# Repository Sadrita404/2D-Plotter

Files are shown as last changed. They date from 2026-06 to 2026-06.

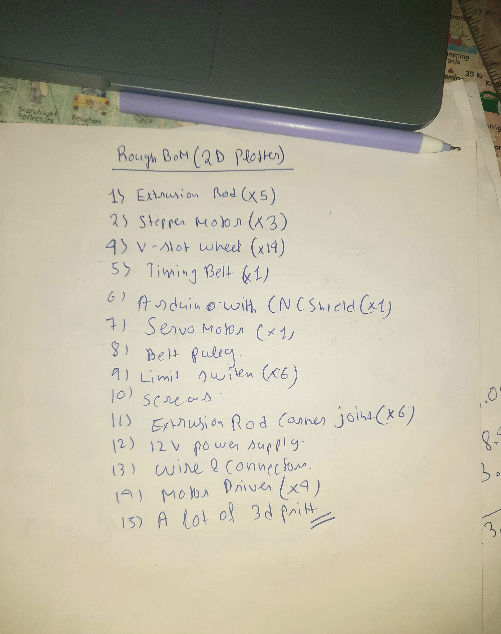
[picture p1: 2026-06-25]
IMAGE/rough BOM.jpg

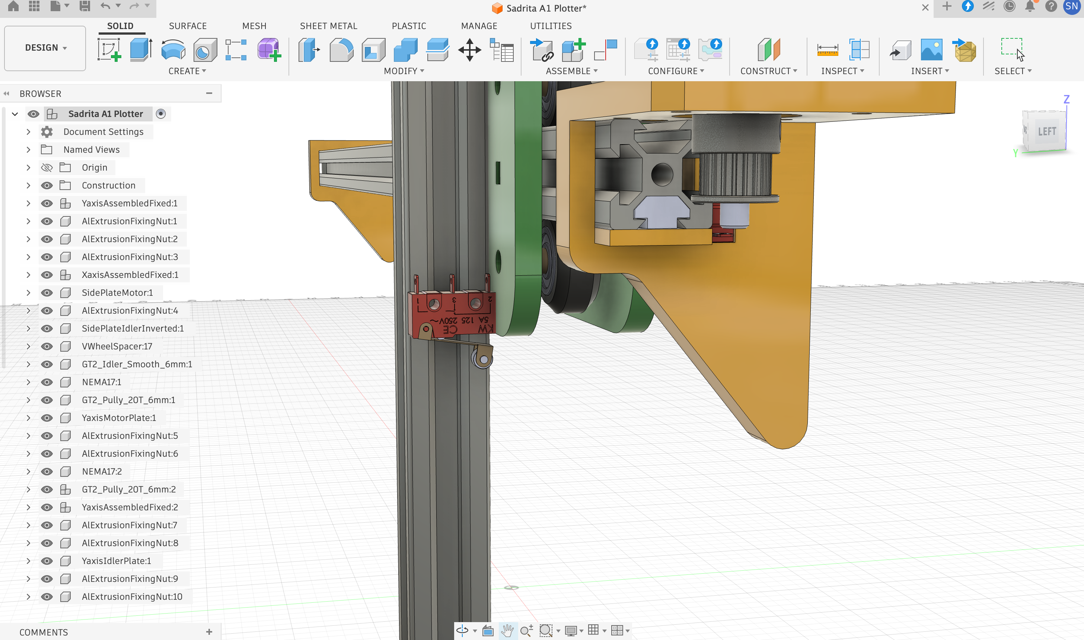
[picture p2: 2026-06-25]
IMAGE/39.png

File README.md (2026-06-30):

|Title | 2D Plotter |
|:-- |:--|
|Author | Sadrita Neogi|

## Overview

It's an hobby grade Pen Plotter which can plot upto A1 size pages and will be efficient to use . It is also very reliable to use it uses grbl software.I have made it open source and anyone can recreate this and also customize it as all the step files are provided . This is made up of 2020 Extrusion Rod with Nema 17 stepper Motor..

### Why I chose this project?
I have choosing this project since it's my from a long time. I have think about that. I want to build and pen plotter. Since whenever I seen this kind of plotted video in any social media, it just fascinated me like how it can just recreate the exact same copy that is on the desktop. So I have chosen this project since I have dream about this project and I like the concept, how the project works, how we can control the coordinates and make changes in the design.

### How to use this project
Use case of this project can be many according to the need, but for my I want to create stunning drawings that cannot be achieved by manually if possible, then it would take many hours, but then I can easily recreate this using this slaughter and also I am very fascinated about drawing about the blueprint of any structure, so it would be great. I can make blueprint of any structured using it since it can easily feed big size pages.

### Rough Sketch

sketch
<p align="center">
  
</p>

<div align="center">

|  | CAD WORK |  |  
| :-: | :-: | :-: |
| CAD Work 7 | CAD Work 11 | CAD Work 18 |
| CAD Work 22 | CAD Work 25 | CAD Work 29 |
| CAD Work 32 | CAD Work 34 | CAD Work 36 |
| CAD Work 39 | CAD Work 42 | CAD Work 47 |
| CAD Work 49 | CAD Work 51 | CAD Work 52 |

</div>

---

## Wiring Diagram 

<p align="center">
  
</p>

## Setup

Once the machine is assembled and wired, firmware needs to be installed so that it can move.

### Flashing GRBL onto the Arduino
GRBL is the firmware which is going to run on the Arduino and interpret the G-code commands. The installation is fairly simple.

1. **Download the Arduino IDE** from their site, a program which allows to flash the Arduino with firmware.
2. **Download GRBL source code** `.zip` file from the GitHub repository: https://github.com/gnea/grbl/releases and unzip the grbl file.  
**Note:** Before we proceed, we need to modify the `config.h` file inside grbl to account for the lack of the Z axis.
3. **Open Arduino IDE and import the grbl file** via: `Sketch` -> `Include Library` -> `Add .ZIP Library...` *(it says .ZIP but the uncompressed file should be chosen)*.
4. **Navigate to the grblUpload sketch** via: `File` -> `Examples` -> `grbl` -> `grblUpload`.
5. **Connect the Arduino to the PC via USB** *(make sure the correct board and port is selected)*.
6. **Flash the sketch** through `Sketch` -> `Upload`.

### For more about the CNC shield - [DOC Link](https://mikroshop.ch/pdf/CNC-Shield-Guide.pdf)
---

### Connecting the Arduino to LaserGRBL
Connecting the Arduino to LaserGRBL (through which I will control the laser) is fairly simple.

1. **Download LaserGRBL** from their website: https://lasergrbl.com and install it.
2. **Connect the Arduino to the computer via USB**.
3. **Choose the correct port** and select **"115200" baud rate**, then click **Connect**.  

If the console shows `Grbl 1.1h`, the chip is connected.

##  Now for sending the G- Code to the Arduino I will use universal Gcode Sender 

**https://github.com/winder/Universal-G-Code-Sender**

- official website - https://winder.github.io/ugs_website/

- It is an open source software, which is used to control CNC machines to send G code to them and to use it

---

## Final Look ( Made in Fusion 360 )

<div align="center">









</div>

<div align="center">
  <h2> Bill of Materials</h2>
</div>

| Name | Purpose | Quantity | Total Cost (USD) | Link | Distributor |
| :--- | :--- | :---: | :---: | :--- | :--- |
| 3.5mm Cylindrical Plastic Spacer | For the Pulley | 1 | 2.76 | [Link](https://onlyscrews.in/products/cylindrical-plastic-spacer-assorted-pack-for-m3-screws) | onlyscrews |
| GT2 Open Loop Timing Belt | For the Pulley | 1 | 4.45 | [Link](https://robu.in/product/5-meter-x-gt2-open-timing-belt-6mm-width/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) | robu |
| Stepper Motor Cable extended | Cable with Connector for NEMA17 Stepper Motor | 3 | 1.40 | [Link](https://robu.in/product/pure-copper-1000-mm-cable-with-connector-for-nema17-stepper-motor/) | robu |
| Extrusion corner bracket | For the Extrusion Rod | 1 | 2.49 | [Link](https://robu.in/product/easymech-cast-corner-bracket-for-20x20-aluminium-profile-silver-4-pcs/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) | robu |
| Cable spiral wrap | For the Cable Protection | 3 | 2.75 | [Link](https://robu.in/product/black-insulated-braid-sleeving-tight-pet-wire-cable-protection-expandable-cable-sleeve-wire-gland/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) | robu |
| Multistrand wire | For the circuit | 2 | 8.51 | [Link](https://robu.in/product/14awg-multicore-insulated-cable3-cores-silicone/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) | robu |
| M5 Nyloc nuts | For the Frame | 20 | 0.25 | [Link](https://onlyscrews.in/products/m5-nyloc-nuts-mild-steel-with-zinc-plating-dia-5mm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) | onlyscrews |
| M3 5mm | For the stepper motor | 20 | 0.35 | [Link](https://onlyscrews.in/products/m3-x-5mm-phillips-pan-head-ss-304-screw-dia-3mm-length-5mm) | onlyscrews |
| M5 X 40mm Hex Bolt | For the Frame | 20 | 1.31 | [Link](https://onlyscrews.in/products/m5-x-40mm-hex-bolt-ss304-dia-5mm-length-40mm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) | onlyscrews |
| M5 Bolts | For the frame | 25 | 3.39 | [Link](https://onlyscrews.in/products/m5-phillips-pan-head-ss304-assorted-box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) | onlyscrews |
| M5 Sliding Nuts | For the 2020 Extrusion Rod | 20 | 1.91 | [Link](https://onlyscrews.in/products/m4-profile-nuts-mild-steel-with-nickel-plating-for-3030-series-t-nut-hammer-nut-1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) | onlyscrews |
| Aluminium Spacer (M5) | For the Pulley | 4 | 4.19 | [Link](https://robu.in/product/lot-aluminium-spacer-5x8mm-7mm-width-silver-4pcs/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) | robu |
| 10mm Spring (ID 5mm) | For the pen holder | 12 | 0.64 | [Link](https://onlyscrews.in/products/od-5mm-free-length-10mm-wire-dia-0-6mm-compression-spring-stainless-steel-304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) | onlyscrews |
| M5 X 45mm Hard Dowel Pins | For the pulley | 20 | 1.91 | [Link](https://onlyscrews.in/products/m5-x-45mm-hard-dowel-pins-dia-5mm-length-45mm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) | onlyscrews |
| 12V 3A power supply | For Power | 1 | 5.59 | [Link](https://robu.in/product/standard-12v-3a-power-supply-with-5-5mm-dc-plug-desktop-type/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) | robu |
| Pin sockets | For Connection | 2 | 0.23 | [Link](https://robu.in/product/2-54mm-1x40-pin-female-single-row-header-strip-pack-of-10/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) | robu |
| JST wire connectors | For the connector | 4 | 1.48 | [Link](https://robu.in/product/jst-xh-2-54mm-4-pin-female-housing-connector/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) | robu |
| JST 4-pin connectors | For Connection | 12 | 1.65 | [Link](https://robu.in/product/4-pin-jst-xh-2-54mm-pitch-plug-and-socket-with-cable-5-pcs/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) | robu |
| JST 3-pin connectors | For the Connection | 12 | 1.52 | [Link](https://robu.in/product/3-pin-jst-xh-2-54mm-pitch-plug-and-socket-with-cable-10-pcs/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) | robu |
| Endstop Switch | For the limit end | 6 | 2.99 | [Link](https://robu.in/product/cnc-3d-printer-mech-endstop-switch/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) | robu |
| A4988 driver Stepper Motor Driver | For the CNC Shield | 3 | 3.97 | [Link](https://robu.in/product/a4988-driver-stepper-motor-driver/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) | robu |
| GT2 5mm Bore Aluminum Pulley Without Teeth | For the belt to move | 8 | 6.12 | [Link](https://www.flyrobo.in/gt2-5mm-bore-aluminum-pulley-without-20-teeth-for-6mm-belt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) | flyrobo |
| GT2 Pulley 20 Teeth 5mm for 6mm | For drive the belt | 4 | 1.08 | [Link](https://robu.in/product/gt2-6mm-belt-width-20-teeth-5mm-bore-timing-pulley/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) | robu |
| SG90 Servo Motor | For the Pen Movement | 1 | 1.55 | [Link](https://robu.in/product/towerpro-sg90-9gm-1-2kg-180-degree-rotation-servo-motor-good-quality/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) | robu |
| CNC Shield V3 | CNC Control Boa | 1 | 1.60 | [Link](https://www.flyrobo.in/cnc-shield-v3-for-engraving-machine-3d-printer-a4988-drv8825-driver-expansion-board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) | flyrobo |
| Arduino Uno | The Main Board | 1 | 2.28 | [Link](https://robu.in/product/arduino-uno-r3-ch340g-atmega328p-devlopment-board/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) | robu |
| GT2 Timing Belt 6mm | For Gantry System | 1 | 6.66 | [Link](https://robu.in/product/10m-gt2-width-6mm-white-open-timing-belt-for-3d-printer/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) | robu |
| V-Slot Idler Pulley | For Gantry System | 14 | 9.20 | [Link](https://www.flyrobo.in/openbuilds-plastic-wheel-idler-pulley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) | flyrobo |
| Nema 17 Bipolar Stepper Motor | The Main Motor | 3 | 40.90 | [Link](https://robu.in/product/fulling-fl42sth38-1684a-nema-17-stepper-motor/) | robu |
| 2020 Aluminium Extrusion | For the Frame | 5 | 37.09 | [Link](https://robu.in/product/easymech-20x20-t-slot-aluminium-extrusion-profile-1500-mm/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) | robu |

<div align="center">
  <table border="0" cellpadding="0" cellspacing="0" style="border-collapse: collapse; max-width: 600px;">
    <tr>
      <td style="background: #ffffff; border: 1px solid #d0d7de; border-radius: 12px; padding: 20px; box-shadow: 0 4px 12px rgba(0,0,0,0.05); font-family: -apple-system, BlinkMacSystemFont, 'Segoe UI', Helvetica, Arial, sans-serif;">
        <div style="font-size: 16px; font-weight: 600; color: #24292f; margin-bottom: 12px; border-bottom: 1px solid #d0d7de; padding-bottom: 8px;">
          Final Bill
        </div>
        <table width="100%" border="0" style="border-collapse: collapse; font-size: 14px; color: #57606a;">
          <tr>
            <td style="padding: 4px 0;">Component Subtotal:</td>
            <td align="right" style="font-weight: 500; color: #24292f;">$160.22</td>
          </tr>
          <tr>
            <td style="padding: 4px 0;"> Shipping:</td>
            <td align="right" style="font-weight: 500; color: #24292f;">$4.2</td>
          </tr>
          <tr>
            <td style="padding: 4px 0; padding-bottom: 8px;"> Tax:</td>
            <td align="right" style="font-weight: 500; color: #24292f;">$5.1</td>
          </tr>
          <tr style="border-top: 1px dashed #d0d7de;">
            <td style="padding: 12px 0 0 0; font-weight: 600; color: #24292f; font-size: 15px;">Net Total Cost:</td>
            <td align="right" style="padding: 12px 0 0 0; font-weight: bold; color: #2da44e; font-size: 18px;">$169.52</td>
          </tr>
          <tr>
            <td style="padding: 2px 0 0 0; font-size: 11px; color: #8c959f;">Projected Budget Allocation:</td>
            <td align="right" style="padding: 2px 0 0 0; font-weight: 500; font-size: 12px; color: #8c959f;">$170</td>
          </tr>
        </table>
      </td>
    </tr>
  </table>
</div>

#### Please approve this project I had put a lot of work in making it.

**Project Under Hack Club**

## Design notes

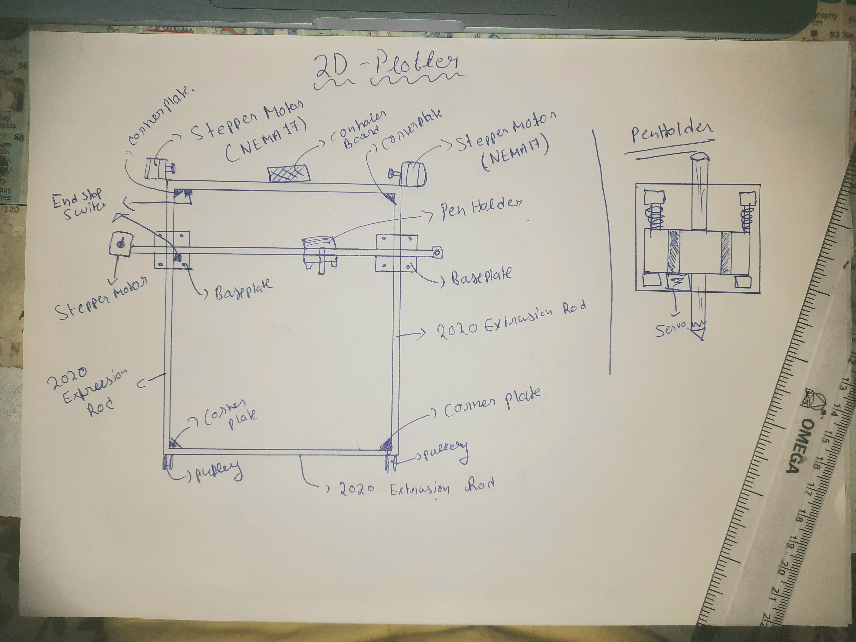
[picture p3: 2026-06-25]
IMAGE/sketch.jpg

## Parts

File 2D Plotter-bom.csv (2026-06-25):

Name | Purpose | Quantity | Total Cost (USD) | Link | Distributor
3.5mm Cylindrical Plastic Spacer | For the Pulley | 1 | 2.76 | https://onlyscrews.in/products/cylindrical-plastic-spacer-assorted-pack-for-m3-screws | onlyscrews
GT2 Open Loop Timing Belt | For the Pulley | 1 | 4.45 | https://robu.in/product/5-meter-x-gt2-open-timing-belt-6mm-width/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 | robu
Stepper Motor Cable extended | Cable with Connector for NEMA17 Stepper Motor | 3 | 1.40 | https://robu.in/product/pure-copper-1000-mm-cable-with-connector-for-nema17-stepper-motor/ | robu
Extrusion corner bracket | For the Extrusion Rod | 1 | 2.49 | https://robu.in/product/easymech-cast-corner-bracket-for-20x20-aluminium-profile-silver-4-pcs/?gad_source=1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 | robu
Cable spiral wrap | For the Cable Protection | 3 | 2.75 | https://robu.in/product/black-insulated-braid-sleeving-tight-pet-wire-cable-protection-expandable-cable-sleeve-wire-gland/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 | robu
Multistrand wire | For the circuit | 2 | 8.51 | https://robu.in/product/14awg-multicore-insulated-cable3-cores-silicone/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 | robu
M5 Nyloc nuts | For the Frame | 20 | 0.25 | https://onlyscrews.in/products/m5-nyloc-nuts-mild-steel-with-zinc-plating-dia-5mm?currency=INR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 | onlyscrews
M3 5mm | For the stepper motor | 20 | 0.35 | https://onlyscrews.in/products/m3-x-5mm-phillips-pan-head-ss-304-screw-dia-3mm-length-5mm | onlyscrews
M5 X 40mm Hex Bolt | For the Frame | 20 | 1.31 | https://onlyscrews.in/products/m5-x-40mm-hex-bolt-ss304-dia-5mm-length-40mm?currency=INR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 | onlyscrews
M5 Bolts | For the frame | 25 | 3.39 | https://onlyscrews.in/products/m5-phillips-pan-head-ss304-assorted-box?currency=INR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 | onlyscrews
M5 Sliding Nuts | For the 2020 Extrusion Rod | 20 | 1.91 | https://onlyscrews.in/products/m4-profile-nuts-mild-steel-with-nickel-plating-for-3030-series-t-nut-hammer-nut-1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 | onlyscrews
Aluminium Spacer (M5) | For the Pulley | 4 | 4.19 | https://robu.in/product/lot-aluminium-spacer-5x8mm-7mm-width-silver-4pcs/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 | robu
10mm Spring (ID 5mm) | For the pen holder | 12 | 0.64 | https://onlyscrews.in/products/od-5mm-free-length-10mm-wire-dia-0-6mm-compression-spring-stainless-steel-304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 | onlyscrews
M5 X 45mm Hard Dowel Pins | For the pulley | 20 | 1.91 | https://onlyscrews.in/products/m5-x-45mm-hard-dowel-pins-dia-5mm-length-45mm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 | onlyscrews
12V 3A power supply | For Power | 1 | 5.59 | https://robu.in/product/standard-12v-3a-power-supply-with-5-5mm-dc-plug-desktop-type/?gad_source=1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 | robu
Pin sockets | For Connection | 2 | 0.23 | https://robu.in/product/2-54mm-1x40-pin-female-single-row-header-strip-pack-of-10/?gad_source=1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 | robu
JST wire connectors | For the connector | 4 | 1.48 | https://robu.in/product/jst-xh-2-54mm-4-pin-female-housing-connector/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 | robu
JST 4-pin connectors | For Connection | 12 | 1.65 | https://robu.in/product/4-pin-jst-xh-2-54mm-pitch-plug-and-socket-with-cable-5-pcs/?gad_source=1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 | robu
JST 3-pin connectors | For the Connection | 12 | 1.52 | https://robu.in/product/3-pin-jst-xh-2-54mm-pitch-plug-and-socket-with-cable-10-pcs/?gad_source=1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 | robu
Endstop Switch | For the limit end | 6 | 2.99 | https://robu.in/product/cnc-3d-printer-mech-endstop-switch/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 | robu
A4988 driver Stepper Motor Driver | For the CNC Shield | 3 | 3.97 | https://robu.in/product/a4988-driver-stepper-motor-driver/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 | robu
GT2 5mm Bore Aluminum Pulley Without Teeth | For the belt to move | 8 | 6.12 | https://www.flyrobo.in/gt2-5mm-bore-aluminum-pulley-without-20-teeth-for-6mm-belt?tracking=ads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 | flyrobo
GT2 Pulley 20 Teeth 5mm for 6mm | For drive the belt | 4 | 1.08 | https://robu.in/product/gt2-6mm-belt-width-20-teeth-5mm-bore-timing-pulley/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 | robu
SG90 Servo Motor | For the Pen Movement | 1 | 1.55 | https://robu.in/product/towerpro-sg90-9gm-1-2kg-180-degree-rotation-servo-motor-good-quality/?gad_source=1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 | robu
CNC Shield V3 | CNC Control Boa | 1 | 1.60 | https://www.flyrobo.in/cnc-shield-v3-for-engraving-machine-3d-printer-a4988-drv8825-driver-expansion-board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 | flyrobo
Arduino Uno | The Main Board | 1 | 2.28 | https://robu.in/product/arduino-uno-r3-ch340g-atmega328p-devlopment-board/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 | robu
GT2 Timing Belt 6mm | For Gantry System | 1 | 6.66 | https://robu.in/product/10m-gt2-width-6mm-white-open-timing-belt-for-3d-printer/?gad_source=1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 | robu
V-Slot Idler Pulley | For Gantry System | 14 | 9.20 | https://www.flyrobo.in/openbuilds-plastic-wheel-idler-pulley?tracking=ads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 | flyrobo
Nema 17 Bipolar Stepper Motor | The Main Motor | 3 | 40.90 | https://robu.in/product/fulling-fl42sth38-1684a-nema-17-stepper-motor/ | robu
2020 Aluminium Extrusion | For the Frame | 5 | 37.09 | https://robu.in/product/easymech-20x20-t-slot-aluminium-extrusion-profile-1500-mm/?gad_source=1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 | robu

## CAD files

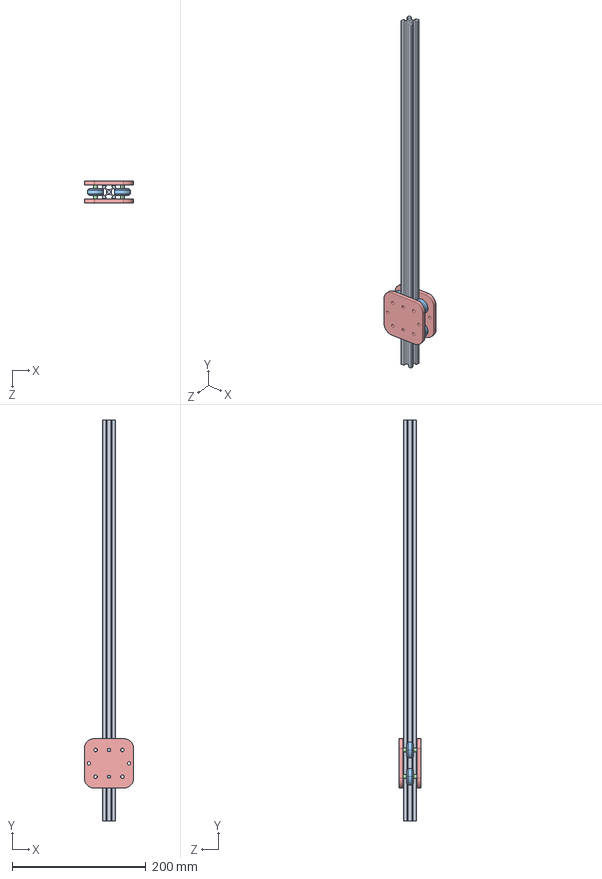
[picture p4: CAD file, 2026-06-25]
CAD/Yaxis Assembled .STEP
74.0 x 600.0 x 33.0 mm
Yaxis350mm
VWheel x 4
VWheelSpacer x 8
XtoYConnectingPlateFixed x 2

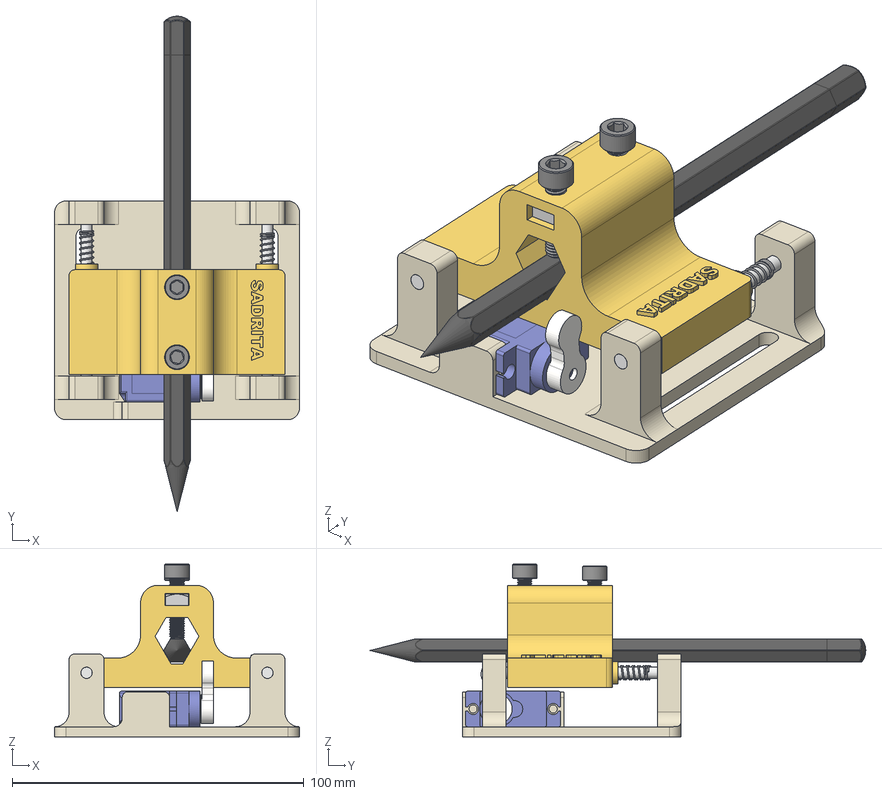
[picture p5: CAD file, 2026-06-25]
CAD/Pen Holder Assembled.step
84.0 x 169.9 x 59.3 mm
Pen_holder_base
9G Servo Motor SG90
Servo_cam
Pen_holder_support
Pen_holder_rod x 2
pencil
spring x 2
96887A112_Low-Strength Steel Square Nut_96887A112 x 2
91290A242_Alloy Steel Socket Head Screw_91290A242 x 2

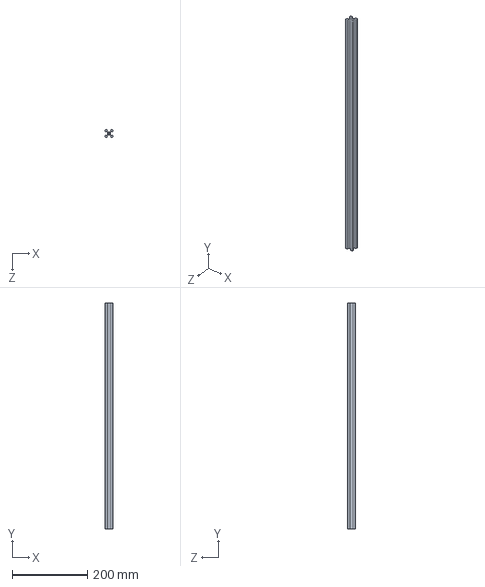
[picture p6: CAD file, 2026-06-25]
CAD/Xaxis.step
20.0 x 600.0 x 20.0 mm

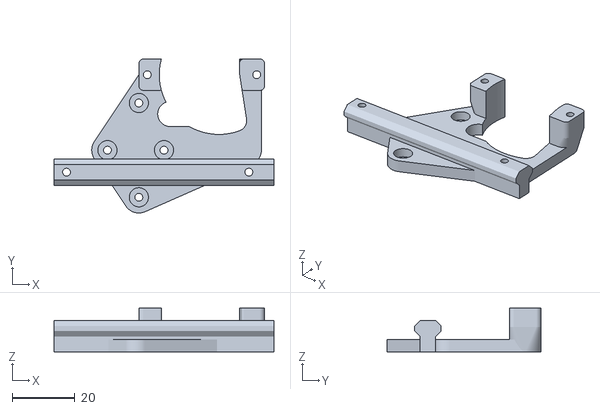
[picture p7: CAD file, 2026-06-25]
STLS/[x2]penLiftBase2.stl
70.0 x 49.0 x 14.0

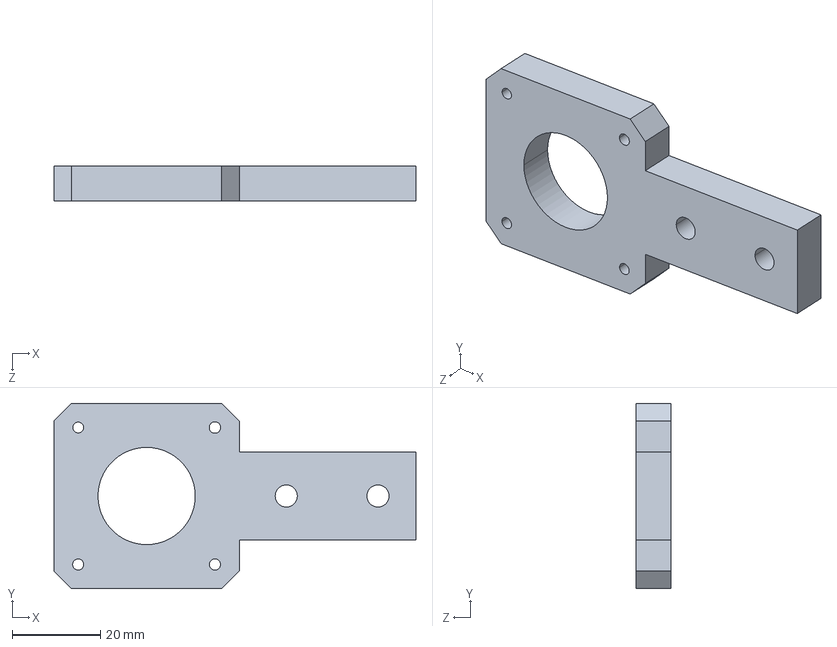
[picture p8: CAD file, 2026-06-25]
CAD/Y-axis MotorPlate.step
81.9 x 41.9 x 8.00 mm

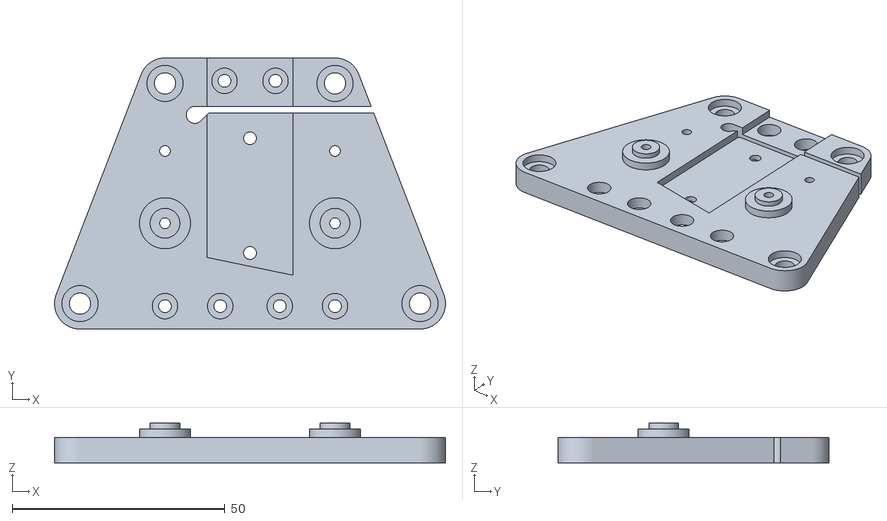
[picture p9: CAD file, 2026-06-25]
STLS/[x1]railBracket.stl
92.0 x 63.8 x 9.30

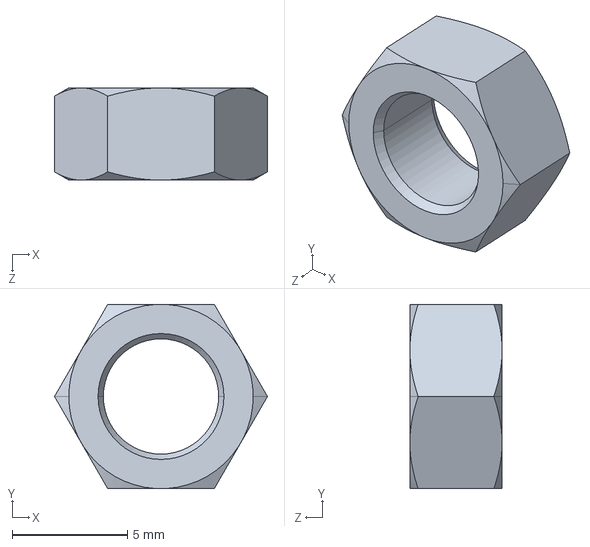
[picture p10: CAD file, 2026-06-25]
CAD/M5Nut.step
9.24 x 8.00 x 4.00 mm

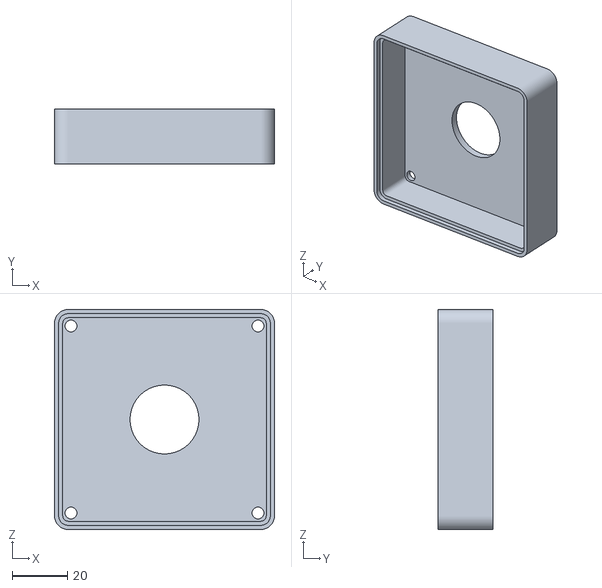
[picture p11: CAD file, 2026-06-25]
STLS/[x1]E-Stop box top.stl
80.0 x 20.0 x 80.0

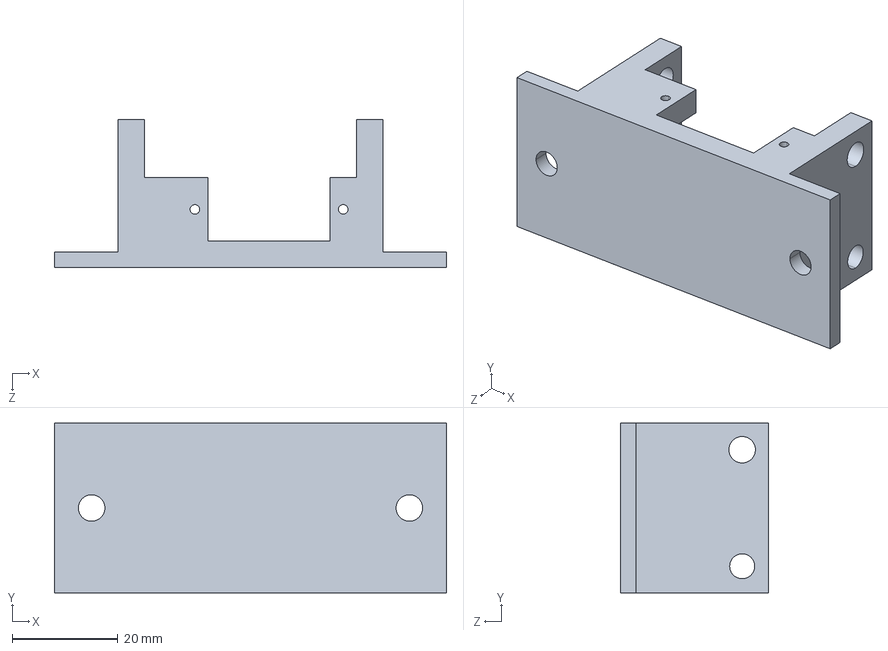
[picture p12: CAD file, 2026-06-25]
CAD/Pen Plate.step
74.0 x 32.0 x 28.0 mm

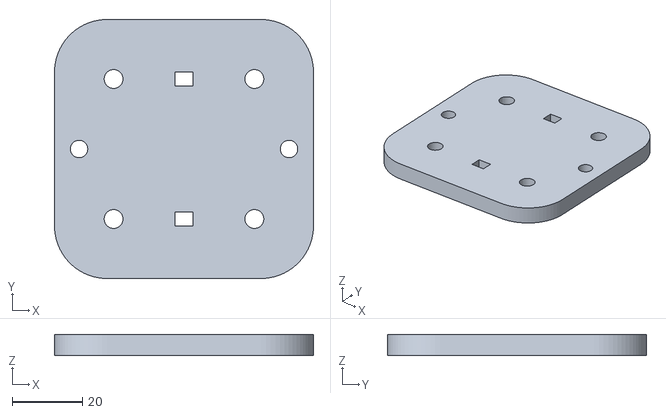
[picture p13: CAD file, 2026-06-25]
STLS/[x2] Lower Plate x-axis.stl
74.0 x 74.0 x 6.00

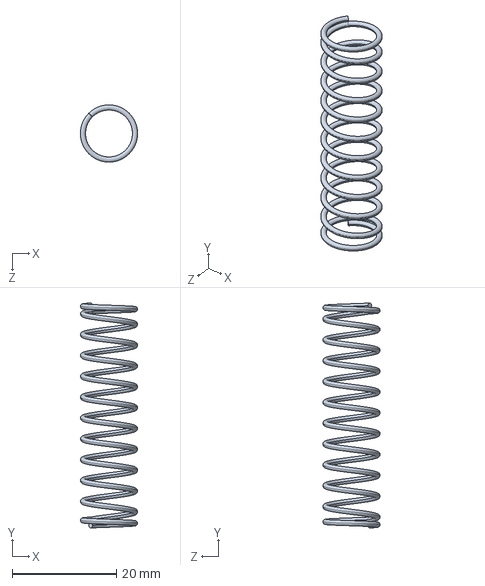
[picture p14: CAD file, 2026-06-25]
CAD/Spring.step
11.0 x 43.2 x 11.0 mm

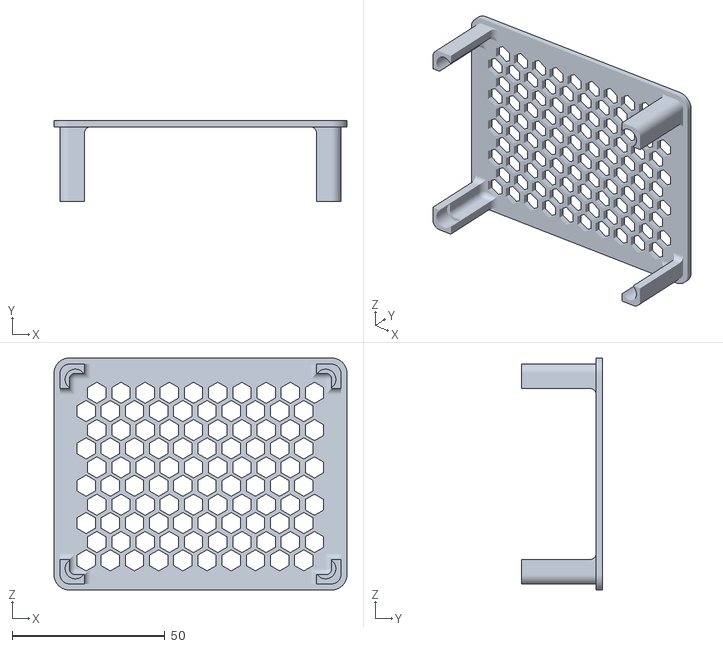
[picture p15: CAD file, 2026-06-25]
STLS/[x1]Enclosrue Lid.stl
96.0 x 26.4 x 76.0

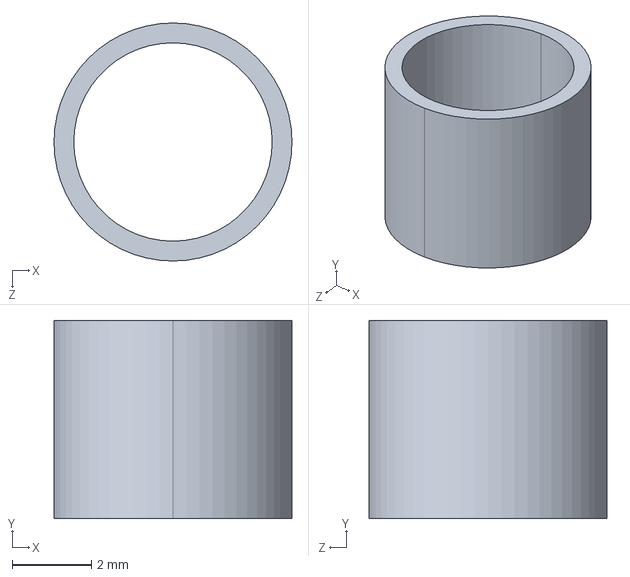
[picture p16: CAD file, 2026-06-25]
CAD/VWheelSpacer.step
6.00 x 5.00 x 6.00 mm

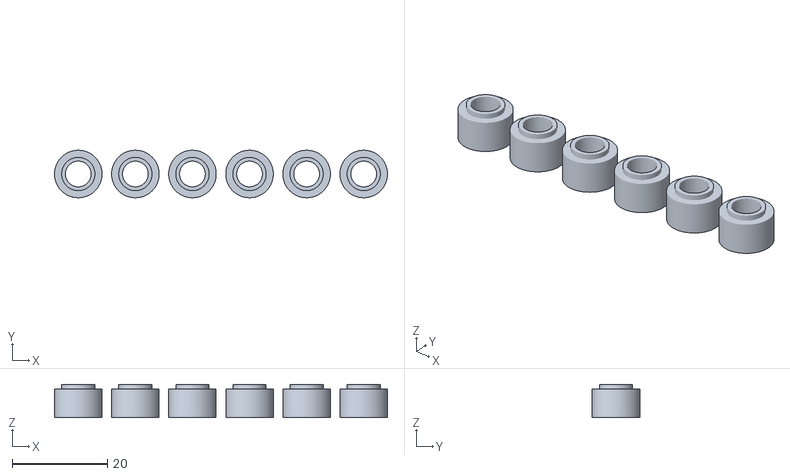
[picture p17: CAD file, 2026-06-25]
STLS/[x2]rollerSpacers-7mm.stl
70.0 x 10.0 x 7.00

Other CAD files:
CAD/X-axis Assembled.STEP
CAD/Pen Shaft.step
STLS/[x2]Motor leg y-axis.stl
CAD/GT2 Pully 20T 6mm.STEP
CAD/Extrusion Corner Bracket.step
CAD/Extrusion Nut.step
CAD/GT2 Idler 6mm.STEP
CAD/Limit Switch.STEP
CAD/ServoSG90.step
CAD/Side Motor Plate.step
CAD/Side Plate Inverted.step
CAD/Side Plate PCB.step
CAD/Side Plate.step
CAD/Uno & CNC Shield Case.step
CAD/VWheel.step
CAD/XtoY Connect Plate.step
CAD/Y-axis Plate.step
CAD/Y-axis350mm.step
STLS/[x1]E-Stop box bottom.stl
STLS/[x1]Enclosure Body.stl
STLS/[x1]Uno and CNC Shield holder.stl
STLS/[x1]cableMounts.stl
STLS/[x1]penCarriage.stl
STLS/[x1]penCarriageBack.stl
STLS/[x1]railBracket-rev.stl
STLS/[x1]railBracketLower.stl
STLS/[x1]railBracketSupport-rev.stl
STLS/[x1]railBracketSupport.stl
STLS/[x2] Left Leg.stl
STLS/[x2] Right Leg.stl
STLS/[x2]Motor Plate.stl
STLS/[x2]Pen Holder Back Plate.stl
STLS/[x2]Pen Holder Front.stl
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

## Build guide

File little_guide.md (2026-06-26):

## This are some of the thing that we need to keep in mind during building this 

For more details follow this - https://lasergrbl.com/usage/arduino-connection/

### I have use an unique way to setup software with extreme precision I went online searching for documentation for product that are available in online shops then I found this one which is listed on Amazon and they have good documentation and for building this kind of project, I think setting up the software with guided would be better
 PDF DOC - https://m.media-amazon.com/images/I/C1yvvKE-JJL.pdf

#### Flashing GRBL onto the Arduino

1. Download the Arduino IDE from their site, a program which allows to flash the Arduino with firmware.
2. Download GRBL source code.zip file from the GitHub repository: https://github.com/gnea/grbl/releases and unzip the grbl file. Before we proceed a we need to modify the config.h file inside grbl to account for the lack of the Z axis.
3. 
Screenshot 2026-06-23 at 2.59.49 AM

## Now , 
Screenshot 2026-06-23 at 3.00.07 AM

1. Open Arduino IDE and import the grbl file via: Sketch->Include Library->add .zip library.
2. Navigate to the grblUpload sketch via: File -> Examples -> grbl -> grblUpload
3. Connect the Arduino to the laptop via USB (make sure the correct board and port is selected).
4. Flash the sketch through Sketch->Upload

After that we need to connect  the Arduino to LaserGRBL(through which I will control the laser) is simple. First, download LaserGRBL from their website: [https://lasergrbl.com](https://lasergrbl.com) and install it. Then again connect the Arduino to the laptop  via USB, choose the correct port and select "115200" baud rate, then click connect. If the console shows "Grbl 1.1h, the chip is connected.

### Now to configure it correctly go through the doc below : - 
[DOC PDF ](https://lasergrbl.com/wp-content/uploads/2020/05/Grbl-Configuration-ENG.pdf)

 #### Key changes Main

### 1) Configuring Stepper Drivers

**Microstepping Jumpers**

Under each stepper driver socket on the CNC Shield V3 are three jumper pairs (MS1, MS2, MS3). These set the microstepping mode:

| MS1 | MS2 | MS3 | Microstepping (A4988) |
| :---: | :---: | :---: | :---: |
| **OFF** | **OFF** | **OFF** | Full step |
| **ON** | **OFF** | **OFF** | 1/2 step |
| **OFF** | **ON** | **OFF** | 1/4 step |
| **ON** | **ON** | **OFF** | 1/8 step |
| **ON** | **ON** | **ON** | 1/16 step |

Most 3018 CNC routers use 1/8 or 1/16 microstepping. Higher microstepping = smoother motion but lower maximum speed (due to GRBL’s step frequency limit). 1/8 stepping is a good balance.

### Setting Current Limit (VREF)
The most critical stepper driver adjustment is current limit. Over-current burns motors and drivers; under-current causes missed steps. Use a multimeter in DC voltage mode:

Measure VREF between the driver’s trimpot (center of the small adjustable potentiometer) and GND.

1)**For A4988: Imax = VREF / 0.625 (with 0.1Ω sense resistors). Set VREF = (rated motor current × 0.625).**

2)**For DRV8825: Imax = VREF / 0.5. Set VREF = (rated motor current / 2).**

3)**Start at 70–80% of motor rated current. For a 1.7A NEMA17: VREF ≈ 0.85V on A4988.**

### 2) GRBL Settings ($ Parameters)

**Type $$ in your GRBL sender to see all current settings. Here are the most important ones:**

| Parameter | Description | Typical Value (3018) |
| :---: | :--- | :--- |
| **$0** | Step pulse time (µs) | 10 |
| **$1** | Step idle delay (ms) | 25 (255 = always on) |
| **$2** | Step port invert (bitmask) | 0 |
| **$3** | Direction port invert (bitmask) | 0 (adjust if axes move wrong direction) |
| **$4** | Step enable invert | 0 |
| **$5** | Limit pin invert (NC vs NO switches) | 0 (NC=1) |
| **$10** | Status report mask | 1 |
| **$20** | Soft limits enable | 0 (1 if homing enabled) |
| **$21** | Hard limits enable | 0 (1 with limit switches) |
| **$22** | Homing cycle enable | 0 (1 with limit switches) |
| **$100** | X steps/mm | 800 (varies by machine) |
| **$101** | Y steps/mm | 800 |
| **$102** | Z steps/mm | 800 |
| **$110** | X max rate (mm/min) | 800 |
| **$111** | Y max rate (mm/min) | 800 |
| **$112** | Z max rate (mm/min) | 400 (Z is slower) |
| **$120** | X acceleration (mm/s²) | 40 |
| **$130** | X max travel (mm) | 300 (your machine’s X range) |

Change any setting by typing the parameter and value, e.g.: $100=800 followed by Enter. Changes are saved to Arduino EEPROM immediately.

### 3) Calibrating Steps Per mm

**Getting steps/mm right is fundamental — incorrect values mean your G-code dimensions do not match reality. Here is the calculation and calibration process:**

```
Steps/mm = (Motor steps per revolution × Microstepping) / (Lead screw pitch mm)

Example: NEMA17 (200 steps/rev) × 1/8 microstepping / 2mm lead pitch
= 200 × 8 / 2 = 800 steps/mm

For belt drive: replace pitch with (belt pitch × pulley teeth)
Example: GT2 belt, 20-tooth pulley → pitch distance = 2mm × 20 = 40mm/rev
Steps/mm = (200 × 16) / 40 = 80 steps/mm
```

### 4)  Homing Switches and Limit Switches

Homing switches allow GRBL to find a consistent machine origin (machine zero) at power-on. Limit switches prevent the machine from crashing into its mechanical ends. These can be the same switches — GRBL supports both modes.

**Switch Types**
- 1) Normally Closed (NC): Switch is closed (circuit active) when not triggered. Opens when the axis reaches the switch. Safer — a broken wire triggers a fault rather than being invisible.

- 2) Normally Open (NO): Switch is open until triggered. Simpler wiring but a broken wire is invisible to GRBL.

**Wiring Limit Switches**
Each axis minimum switch connects to the Xmin, Ymin, Zmin headers on the CNC shield. Connect one switch terminal to the signal pin and the other to GND. No pull-up resistors are needed — the CNC shield or Arduino provides internal pull-ups on limit inputs.

#### Enabling Homing

```
$22=1   ; Enable homing cycle
$23=0   ; Homing direction mask (0 = home to -X, -Y, +Z)
$24=25  ; Homing feed rate (mm/min) - slow speed for switch contact
$25=500 ; Homing seek rate (mm/min) - fast approach speed
$26=250 ; Homing debounce delay (ms)
$27=1   ; Homing pull-off distance (mm) - backs off switch after homing
$21=1   ; Enable hard limits (optional - halts machine if limit hit)
$20=1   ; Enable soft limits (requires homing to be done first)

```

After enabling homing, type $H to run the homing cycle. The machine will seek each axis minimum (or maximum for Z) at the seek rate, back off, and re-approach slowly for accurate repeatability.

### This are some of the comands that I learn during, searching about the software 

**Key G-code Commands to Know**

```
G28       ; Return to home (machine zero)
G0 X0 Y0  ; Rapid move to work zero (X=0, Y=0)
G1 Z-1 F100  ; Feed move: cut 1mm into material at 100mm/min
G91       ; Set incremental positioning mode
G90       ; Set absolute positioning mode (default)
M3 S1000  ; Spindle on clockwise at 1000 RPM (if spindle is PWM-controlled)
M5        ; Spindle off
```

##  Now for sending the G- Code to the Arduino I will use universal Gcode Sender 

**https://github.com/winder/Universal-G-Code-Sender**

- official website - https://winder.github.io/ugs_website/

- It is an open source software, which is used to control CNC machines to send G code to them and to use it

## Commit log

2026-06-25 all cad step file added
    [Extrusion Corner Bracket.step, Extrusion Nut.step, GT2 Idler 6mm.STEP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]
2026-06-25 all 3d print stl added
    [[x1]E-Stop box bottom.stl, [x1]E-Stop box top.stl, [x1]Enclosrue Lid.stl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]
2026-06-25 Bill of Material Added
    [2D Plotter-bom.csv]
